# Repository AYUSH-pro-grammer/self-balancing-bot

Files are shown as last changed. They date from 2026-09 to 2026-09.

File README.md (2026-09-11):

# Self Balancing Robot 

This is a built two-wheeled robot which balances itself using an ESP32 and MPU-9250 IMU sensor and two IBT-2 motor drivers

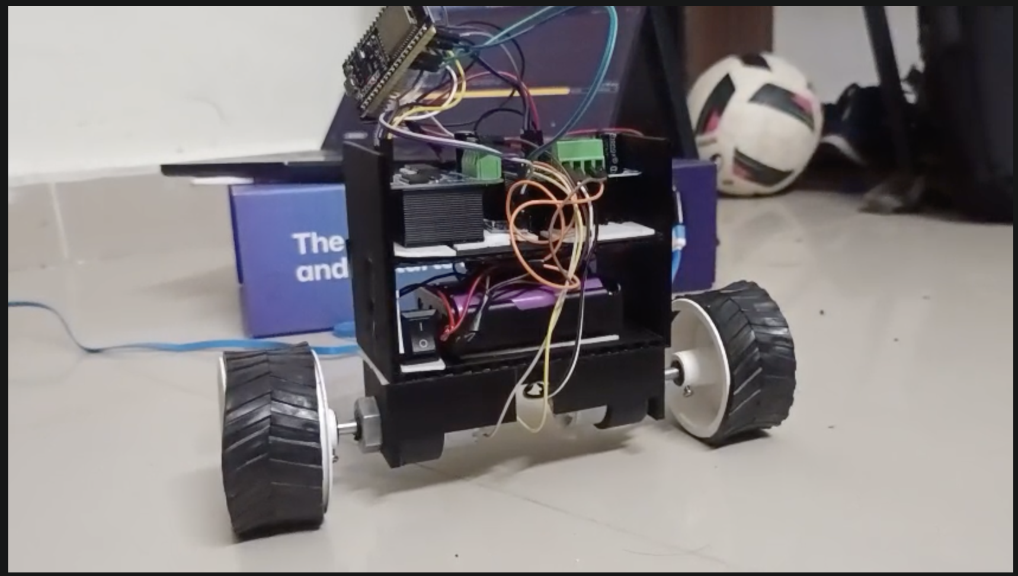
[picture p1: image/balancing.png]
Robot balancing


## What is it?

It is a two-wheeled robot that stays upright by sensing its tilt with the IMU and adjusting motor speed accordingly. The ESP32 reads data about acceleration and angular velocity from the IMU. It then calculates how much the robot is tilting using a filter. Based on this angle it controls both DC motors to keep the robot balanced

The self-balancing robot works like a pendulum:

```text

Robot tilts → IMU senses changes → ESP32 calculates angle

→ PID calculates control → Motor controls → Robot balanced

```

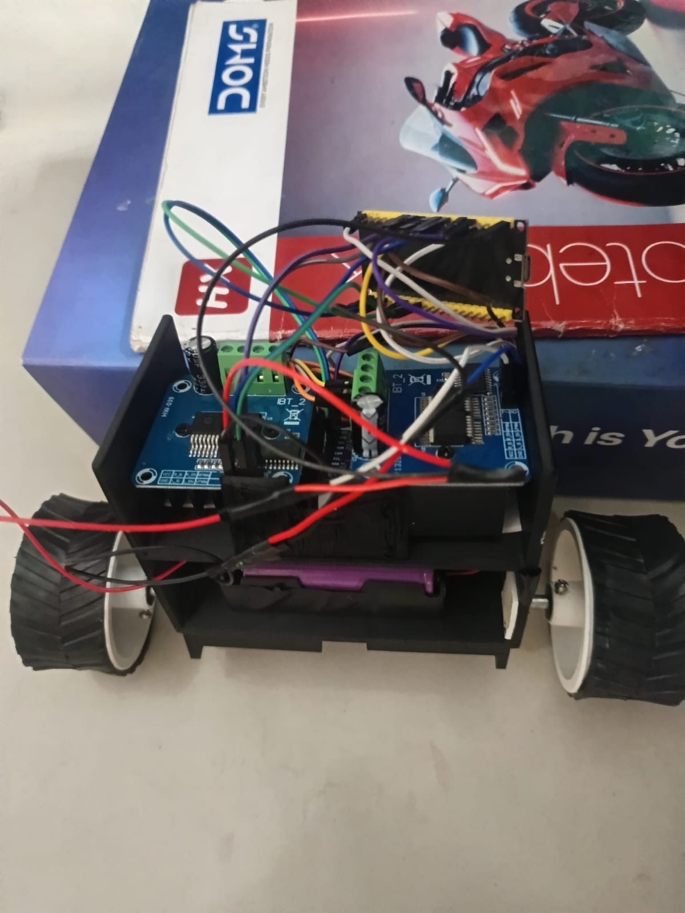
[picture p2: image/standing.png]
Robot standing


## Why I built it?

I wanted to build a project that combines design, electronics, sensors, motor control and programming. Self-balancing robots are interesting because both the physical structure and the software code directly affect how well the robot performs.

## Hardware

| Component | Quantity |
| --- | ----: |
| ESP32 DOIT DevKit V1 | 1 |
| GY-9250 / MPU-9250 IMU | 1 |
| BTS7960 / IBT-2 Motor Driver | 2 |
| 12V DC Gear Motor | 2 |
| Wheels | 2 |
| 18650 Li-ion Battery | 3 |
| 12V → 5V Buck Converter | 1 |
| Custom 3D-Printed Chassis | 1 |
| Wiring and Connectors | 1 set |

## Wiring

<!-- ![Circuit diagram](image/circuit.png) -->
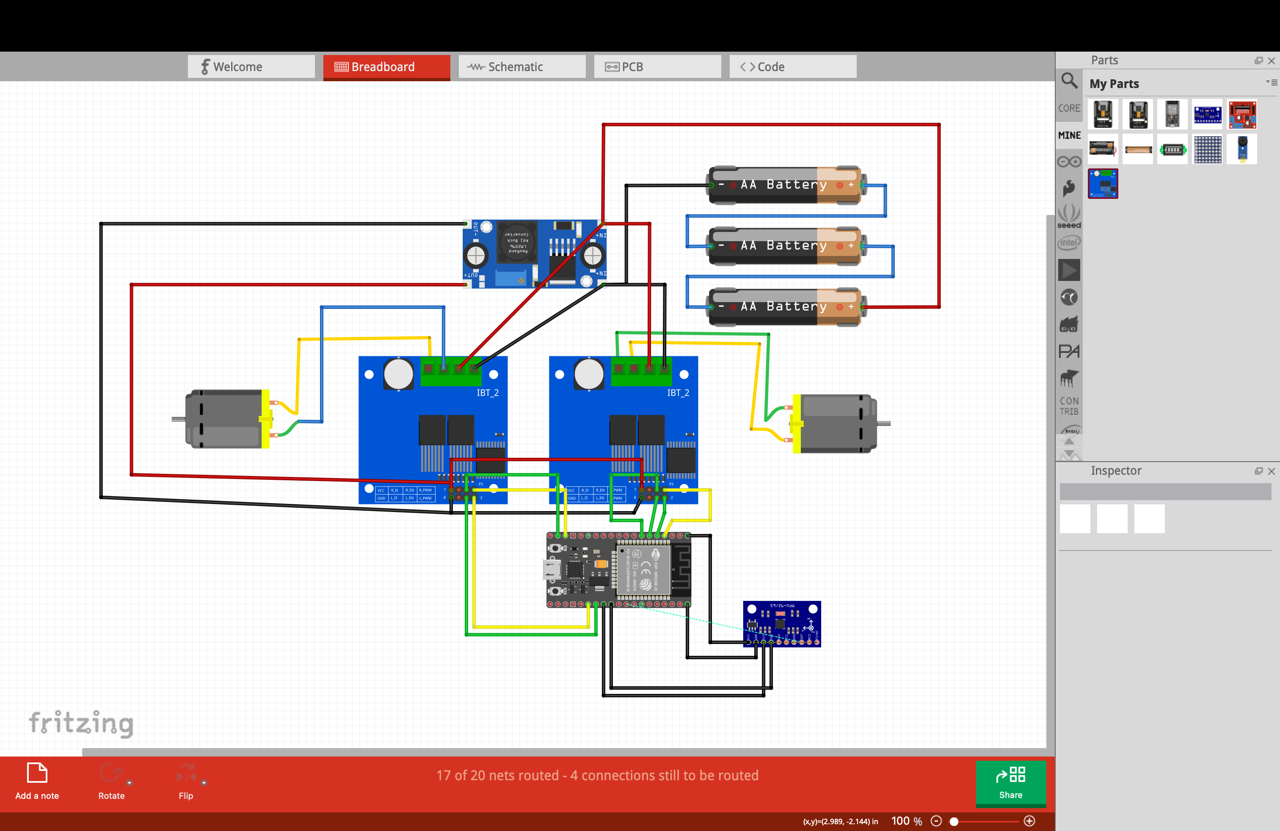
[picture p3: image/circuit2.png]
Circuit diagram


## Cad

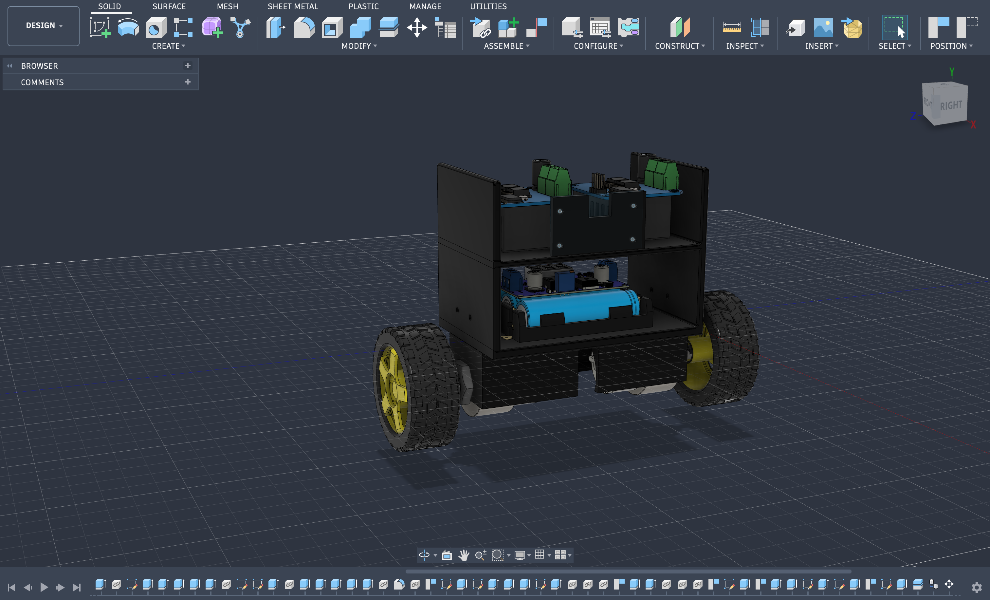
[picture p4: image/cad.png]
Cad Image


### MPU-9250 → ESP32

| MPU-9250 | ESP32 |
| --- | --- |
| VCC | 3.3V |
| GND | GND |
| SDA | GPIO 21 |
| SCL | GPIO 22 |

The MPU-9250 communicates via I²C at address `0x68`.

### Motor Driver #1 → ESP32

| IBT-2 Pin | ESP32 |
| --- | --- |
| RPWM | GPIO 25 |
| LPWM | GPIO 26 |
| R_EN | GPIO 27 |
| L_EN | GPIO 13 |
| GND | GND |
| VCC | 5V |

Motor 1 connects to `M+` and `M-`.

### Motor Driver #2 → ESP32

| IBT-2 Pin | ESP32 |
| --- | --- |
| RPWM | GPIO 32 |
| LPWM | GPIO 33 |
| R_EN | GPIO 14 |
| L_EN | GPIO 19 |
| GND | GND |
| VCC | 5V |

Motor 2 connects to `M+` and `M-`.

## Power

The 12V battery powers the motor drivers directly:

```text

Battery + → IBT-2 #1 B+

→ IBT-2 #2 B+

→ Buck IN+

Battery. → IBT-2 #1 B-

→ IBT-2 #2 B-

→ Buck IN-

```

The buck converter provides 5V:

```text

Buck 5V → ESP32 5V/VIN

→ IBT-2 #1 VCC

→ IBT-2 #2 VCC

```

All grounds must be connected together:

```text

Battery. + Buck GND + ESP32 GND. Both IBT-2 GND

```

## Firmware

The firmware is located at:

```text

firmware/main.cpp

```

It does the following:

Reads the MPU-9250 over I²C

Calibrates the gyroscope

Computes the robots tilt angle

Applies a complementary filter

Uses a PID control algorithm

Controls both motors

Stops motors if the robot tilts beyond an angle

The code is compiled for:

```text

DOIT ESP32 DEVKIT V1

```

Open the monitor at 115200 baud. When starting hold the robot steady so the IMU can calibrate properly.

## PID

The robot compares its angle to a target angle and uses PID control to fix any error:

```text

PID = (Kp × Error). Ki × Integral) + (Kd × Derivative)

```

Actual values used:

```cpp

targetAngle = 3.46;

Kp = 10.0;

Ki = 0.0;

Kd = 0.5;

```

These values may change depending on versions of the robot.

## CAD

The CAD files are in:

```text

cad/self balancing.f3z

cad/self balancing.step

```

The CAD model shows the mechanical design of the robot.

## Videos

### Working

[`video/working/video-w-1.mp4`](video/working/video-w-1.mp4)

### Testing

[`video/testing/video-f-1.mp4`](video/testing/video-f-1.mp4)

[`video/testing/video-f-2.mp4`](video/testing/video-f-2.mp4)

## Bill of Materials

A full BOM is in:

[`bom.csv`](bom.csv)

##  Components

| Components | Quantity | Purchase Link |
| --- | --- | --- |
| ESP32 DOIT DevKit V1 | 1 | [Robu.in Link](https://robu.in/product/wroom-32-esp32-wifi-bt-ble-mcu-module/) |
| GY-9250 / MPU-9250 | 1 | [Robokits Link](https://robokits.co.in/sensors/gyroscope-and-inertial-imu/9dof-3-axis-accelerometer-gyroscope-magnetometer-gy-9250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) |
| BTS7960 / IBT-2 Motor Driver | 2 | [Robu.in Link](https://robu.in/product/bts7960-43a-h-bridge-high-power-stepper-motor-driver-module/) |
| 12V DC Gear Motor | 2 | [Robocraze Link](https://robocraze.com/products/200-geared-motor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) |
| Wheels | 2 | [Robomart Link](https://robomart.com/product/5x2-wheel-robotic-tyre-for-robotics-diy-for-dc-gear-motor-5x2-cm/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) |
| 18650 Li-ion Battery | 3 | [Electronicspices Link](https://electronicspices.com/product/18650-2600mah-3-65v-lithium-ion-cell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) |
| 12V → 5V Buck Converter | 1 | [RajivElectronics Link](https://rajivelectronics.com/product/lm2596-dc-dc-buck-converter-adjustable-step-down-module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) |
| 3D Printed Chassis | 1 | Custom design included in the [`cad`](cad/) folder |

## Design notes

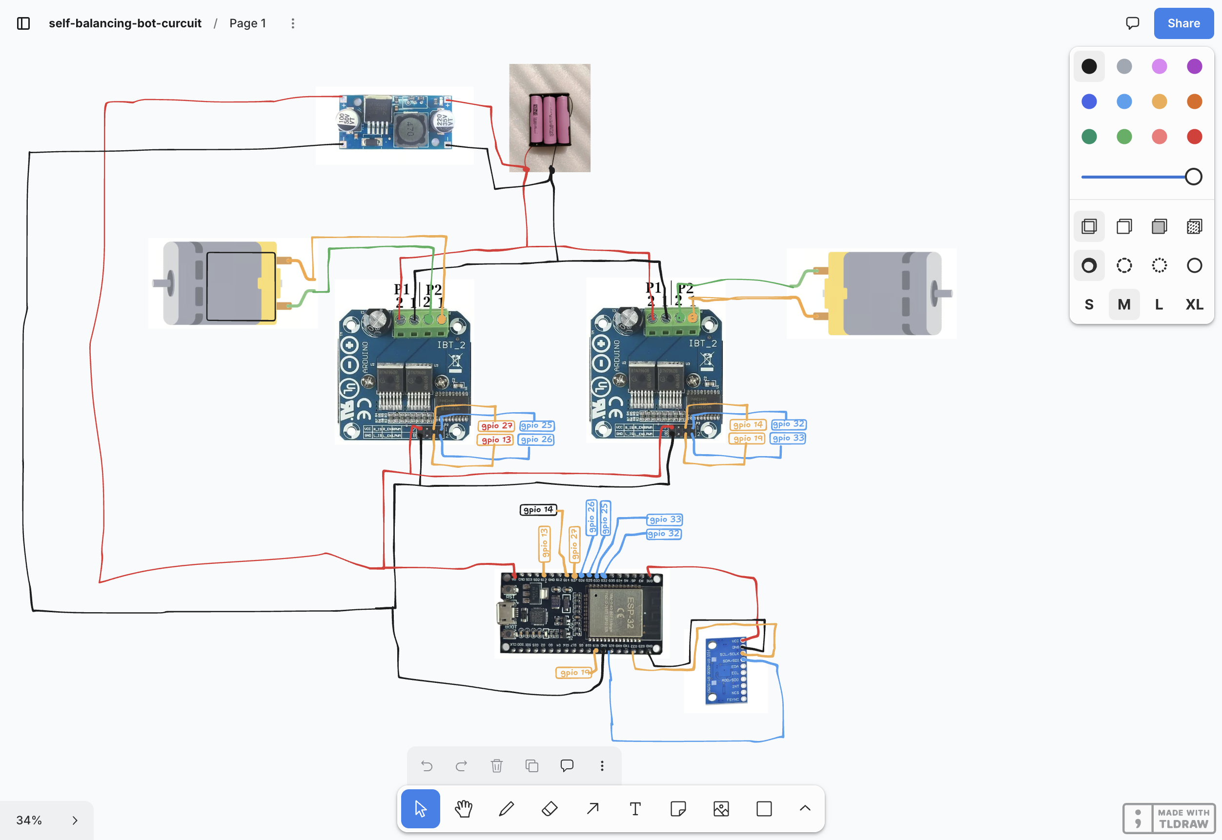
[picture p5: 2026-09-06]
image/circuit.png

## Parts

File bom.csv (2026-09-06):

Item | Quantity | Description | Unit Cost (INR) | Total Cost (INR) | Purchase Link
ESP32 1 | 1.0 | Main microcontroller | 500.0 | 500.0 | https://robu.in/product/esp-wroom-32-esp32-wifi-bt-ble-mcu-module/
GY-9250 MPU-9250 | 1.0 | 9-axis IMU | 350.0 | 350.0 | https://robokits.co.in/sensors/gyroscope-and-inertial-imu/9dof-3-axis-accelerometer-gyroscope-magnetometer-gy-9250
BTS7960 IBT-2 Motor Driver | 2.0 | High current DC motor driver | 350.0 | 700.0 | https://robu.in/product/double-bts7960-43a-h-bridge-high-power-stepper-motor-driver-module/
12V DC Gear Motor | 2.0 | Drive motor | 150.0 | 300.0 | https://robocraze.com/products/200-rpm-geared-motor?variant=40192492601497&country=IN&currency=INR
Wheels | 2.0 | Wheels for drive motors | 60.0 | 120.0 | https://robomart.com/product/5x2-wheel-robotic-tyre-for-robotics-diy-for-dc-gear-motor-5x2-cm/
3.7V Battery 18650 | 3.0 | Main power source | 129.0 | 387.0 | https://electronicspices.com/product/18650-2600mah-3-65v-cylindrical-lithium-ion-cell
12V to 5V Buck Converter | 1.0 | Logic power converter | 60.0 | 60.0 | https://rajivelectronics.com/product/lm2596-dc-dc-buck-converter-adjustable-step-down-module
TOTAL |  |  |  | 2417.0

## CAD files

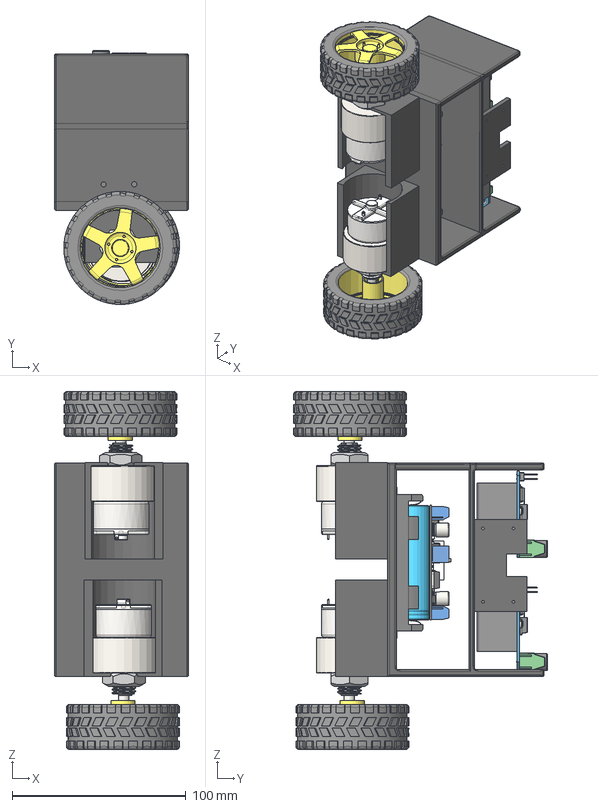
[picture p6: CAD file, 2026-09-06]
cad/self balancing.step
77.1 x 146.0 x 205.9 mm
BatteryCasePlastic
BatteryCaseSpring x 6
Battery18650 x 3

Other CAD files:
cad/self balancing.f3z

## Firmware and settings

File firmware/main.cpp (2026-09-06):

#include <Wire.h>
#include <math.h>

#define MPU_ADDR 0x68

// motor 1
#define M1_RPWM 25
#define M1_LPWM 26
#define M1_REN  27
#define M1_LEN  13

// motor 2
#define M2_RPWM 32
#define M2_LPWM 33
#define M2_REN  14
#define M2_LEN  19


float targetAngle = 3.46;

float Kp = 10.0;         
float Ki = 0.0;          
float Kd = 0.5;        
int minMotorSpeed = 0;  


unsigned long prevTime = 0;
unsigned long lastPrintTime = 0;
float currentAngle = 0.0;
float pidError = 0, pidIntegral = 0, pidDerivative = 0, prevError = 0;
float pidOutput = 0;
int motorSpeed = 0;


float gyroX_offset = 0;
float accelY_offset = 0;

void writeRegister(byte reg, byte value) {
  Wire.beginTransmission(MPU_ADDR);
  Wire.write(reg);
  Wire.write(value);
  Wire.endTransmission();
}

void setup() {
  Serial.begin(115200);
  Wire.begin(21, 22);
  Wire.setClock(400000); 

  writeRegister(0x6B, 0x00); 
  writeRegister(0x1C, 0x00); 
  writeRegister(0x1B, 0x00); 

  pinMode(M1_RPWM, OUTPUT);
  pinMode(M1_LPWM, OUTPUT);
  pinMode(M1_REN, OUTPUT);
  pinMode(M1_LEN, OUTPUT);

  pinMode(M2_RPWM, OUTPUT);
  pinMode(M2_LPWM, OUTPUT);
  pinMode(M2_REN, OUTPUT);
  pinMode(M2_LEN, OUTPUT);

  digitalWrite(M1_REN, HIGH);
  digitalWrite(M1_LEN, HIGH);
  digitalWrite(M2_REN, HIGH);
  digitalWrite(M2_LEN, HIGH);

  Serial.println("\n[SYSTEM] Calibrating IMU... Keep the robot still on flat ground!");
  delay(1500);

  long gx_sum = 0;
  long ay_sum = 0;
  const int samples = 500;

  for (int i = 0; i < samples; i++) {
    Wire.beginTransmission(MPU_ADDR);
    Wire.write(0x3B);
    Wire.endTransmission(false);
    Wire.requestFrom(MPU_ADDR, 14);

    if (Wire.available() == 14) {
      Wire.read(); Wire.read(); 
      int16_t ay = Wire.read() << 8 | Wire.read();
      Wire.read(); Wire.read(); 
      Wire.read(); Wire.read(); 
      int16_t gx = Wire.read() << 8 | Wire.read();
      Wire.read(); Wire.read(); 
      Wire.read(); Wire.read(); 

      gx_sum += gx;
      ay_sum += ay;
    }
    delay(2);
  }

  gyroX_offset = (float)gx_sum / samples;
  accelY_offset = (float)ay_sum / samples;

  Serial.print("[SYSTEM] Calibrated. GyroX Offset: ");
  Serial.println(gyroX_offset);
  Serial.println("[SYSTEM] Ready. Balancing active.");

  prevTime = micros();
}

void loop() {
  unsigned long currentTime = micros();
  float dt = (currentTime - prevTime) / 1000000.0;
  if (dt < 0.010) {
    return; 
  }
  prevTime = currentTime;

  Wire.beginTransmission(MPU_ADDR);
  Wire.write(0x3B);
  Wire.endTransmission(false);
  Wire.requestFrom(MPU_ADDR, 14);

  if (Wire.available() == 14) {
    Wire.read(); Wire.read(); 
    int16_t ay = Wire.read() << 8 | Wire.read();
    int16_t az = Wire.read() << 8 | Wire.read();
    Wire.read(); Wire.read(); 
    int16_t gx = Wire.read() << 8 | Wire.read();
    Wire.read(); Wire.read(); 
    Wire.read(); Wire.read(); 

    float accelAngle = atan2((float)ay - accelY_offset, (float)az) * 180.0 / PI;
    float gyroRate = ((float)gx - gyroX_offset) / 131.0;

    currentAngle = 0.98 * (currentAngle + gyroRate * dt) + 0.02 * accelAngle;

    pidError = targetAngle - currentAngle;
    pidIntegral += pidError * dt;
    pidIntegral = constrain(pidIntegral, -300, 300); 

    pidDerivative = (pidError - prevError) / dt;
    pidOutput = (Kp * pidError) + (Ki * pidIntegral) + (Kd * pidDerivative);
    prevError = pidError;

    if (abs(pidOutput) > 1.0) {
      motorSpeed = abs(pidOutput) + minMotorSpeed;
    } else {
      motorSpeed = 0;
    }
    motorSpeed = constrain(motorSpeed, 0, 255);

    if (abs(currentAngle - targetAngle) > 40.0) {
      motorSpeed = 0;
      pidIntegral = 0;
    }

    if (pidOutput > 0) {
      analogWrite(M1_RPWM, motorSpeed);
      analogWrite(M1_LPWM, 0);
      analogWrite(M2_RPWM, motorSpeed);
      analogWrite(M2_LPWM, 0);
    } else if (pidOutput < 0) {
      analogWrite(M1_RPWM, 0);
      analogWrite(M1_LPWM, motorSpeed);
      analogWrite(M2_RPWM, 0);
      analogWrite(M2_LPWM, motorSpeed);
    } else {
      analogWrite(M1_RPWM, 0);
      analogWrite(M1_LPWM, 0);
      analogWrite(M2_RPWM, 0);
      analogWrite(M2_LPWM, 0);
    }
  }


  if (millis() - lastPrintTime >= 100) {
    lastPrintTime = millis();
    Serial.print("Angle: ");
    Serial.print(currentAngle, 2);
    Serial.print(" deg | PWM: ");
    Serial.println(motorSpeed);
  }
}
